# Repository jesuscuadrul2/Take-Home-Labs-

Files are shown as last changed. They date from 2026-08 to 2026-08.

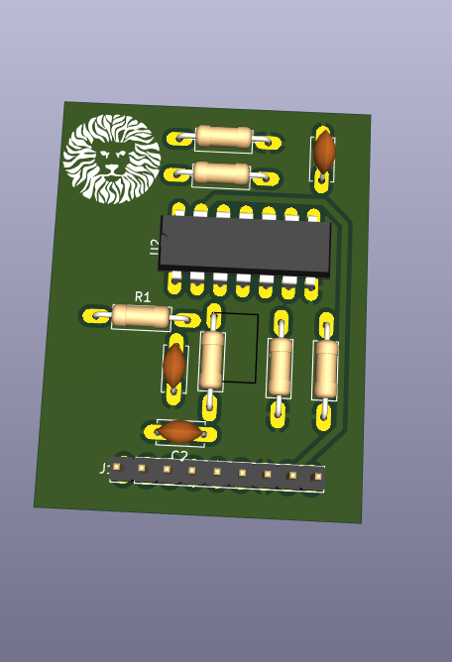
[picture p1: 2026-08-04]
Images/Planta_RC/3D View.png

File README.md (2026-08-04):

# 🔬 Take-Home Labs: Plataforma de Control con Arduino Mega (ATmega2560)






Este repositorio contiene el desarrollo, documentación y código fuente de una serie de laboratorios experimentales centrados en la arquitectura del microcontrolador ATmega2560. El proyecto se articula en torno a una **Shield personalizada diseñada en KiCad**, la cual integra tres plantas físicas intercambiables orientadas a la validación de estrategias de adquisición de señales, instrumentación y control en lazo cerrado.

## 🎯 Objetivo General

Desarrollar competencias avanzadas en la programación de sistemas embebidos priorizando el control directo del hardware a bajo nivel. El proyecto cierra la brecha entre el diseño electrónico (esquemáticos y PCB) y el desarrollo de firmware, validando iterativamente plantas físicas reales.

## 🛠️ Arquitectura de Hardware (KiCad PCB Shield)

La placa base fue diseñada con un enfoque altamente modular. La distribución de señales PWM, analógicas y digitales se realiza a través de **pin sockets modulares (como el conector principal J2 y los puertos dedicados J10, J13, J15)**, permitiendo acoplar diferentes plantas de manera dinámica. 

El sistema cuenta con una topología de potencia robusta:

*   **Gestión de Energía:** Entrada principal de 15V (vía Barrel Jack o PD Trigger) acondicionada a 12V mediante un regulador ajustable **LM350 (TO-220)**. 
*   **Regulación en Cascada:** Etapas secundarias aisladas a 5V (L7805) y 9V (L7809) provistas de capacitores de desacoplo para garantizar rizado mínimo en las etapas analógicas.
*   **Interfaz Humano-Máquina:** Integración en placa de un Encoder Rotativo con filtrado de hardware anti-rebote (redes RC de 100nF) para navegación de menús.

## 🕹️ Descripción Técnica de las Plantas

### 1. Planta de Enrutamiento y Dinámica (CD4066)

*   **Arquitectura:** Matriz de conmutación de señales analógicas basada en arreglos de interruptores bilaterales **CD4066BE**.
*   **Comportamiento Dinámico:** Integra tres redes RC en cascada (1 MΩ y 1 µF) controladas digitalmente con resistencias de *pulldown* (10k). Permite modificar la función de transferencia del sistema en tiempo real, ajustando la respuesta transitoria según las etapas activadas por el microcontrolador.

### 2. Planta Electromecánica (Motor DC N20)

*   **Actuación:** Modulación de velocidad mediante un MOSFET de canal N (Q1) excitado por señal PWM, con una resistencia de *pulldown* (10k) en la puerta y un diodo de giro libre (Flyback D7) para suprimir picos inductivos del motor a 12V.
*   **Telemetría:** Integración directa de un encoder de cuadratura que proporciona datos de posición y velocidad (conectado al header J10), habilitando la implementación de algoritmos PID en lazo cerrado.

### 3. Planta de Visualización e Instrumentación (LM3914N)

*   **Interfaz Visual:** Vúmetro analógico basado en el driver **LM3914N** alimentado a 9V, que excita una barra de 10 segmentos LED (HDSP-4830) de forma lineal.
*   **Acondicionamiento de Señal:** Para visualizar la salida digital del Arduino, incorpora un filtro pasa-bajas RC (resistencia de 4.7 kΩ y capacitor de 10 µF) que convierte el tren de pulsos PWM en una señal DC estable, garantizando una lectura continua sin parpadeos visuales. El rango de referencia es calibrable mediante un potenciómetro de 5k.

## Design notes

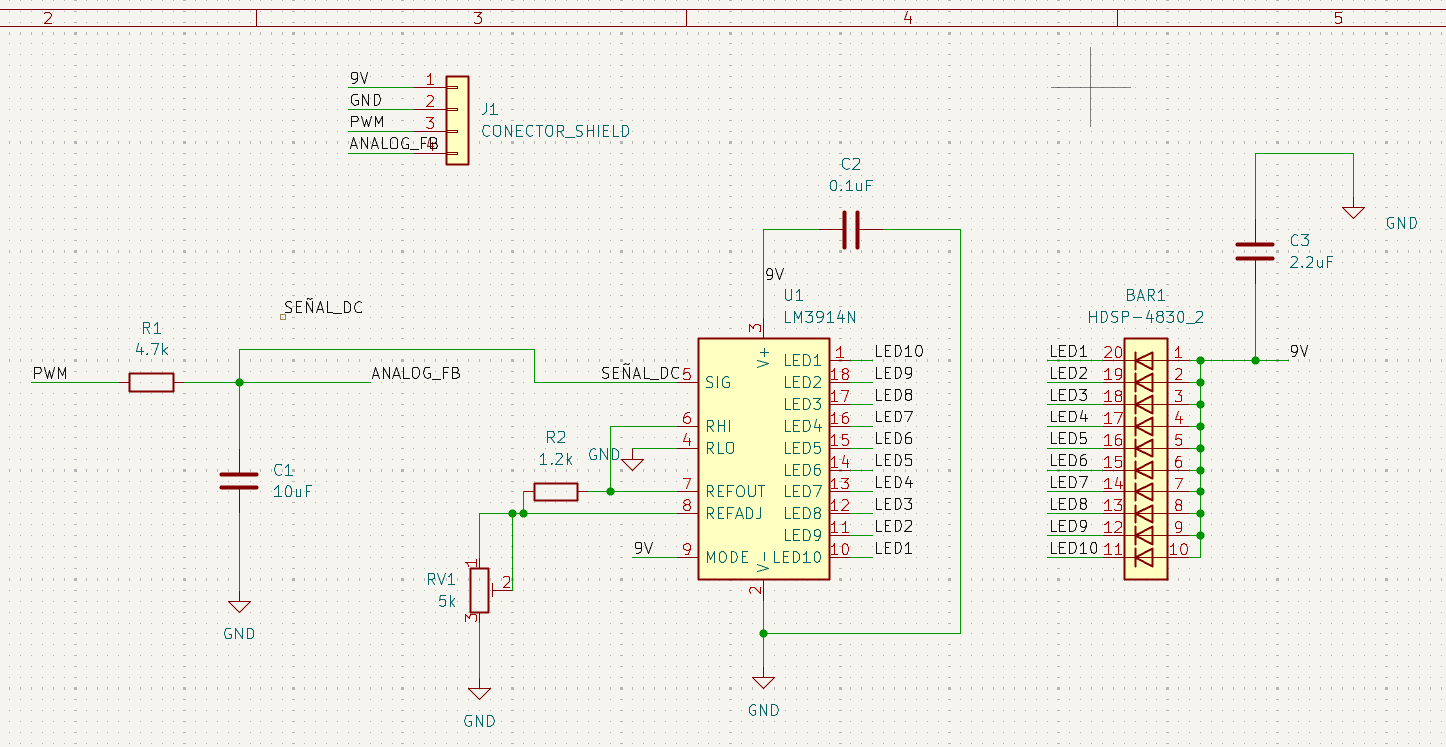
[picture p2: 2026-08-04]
Images/Planta_Barra_Led-/Schematics.png

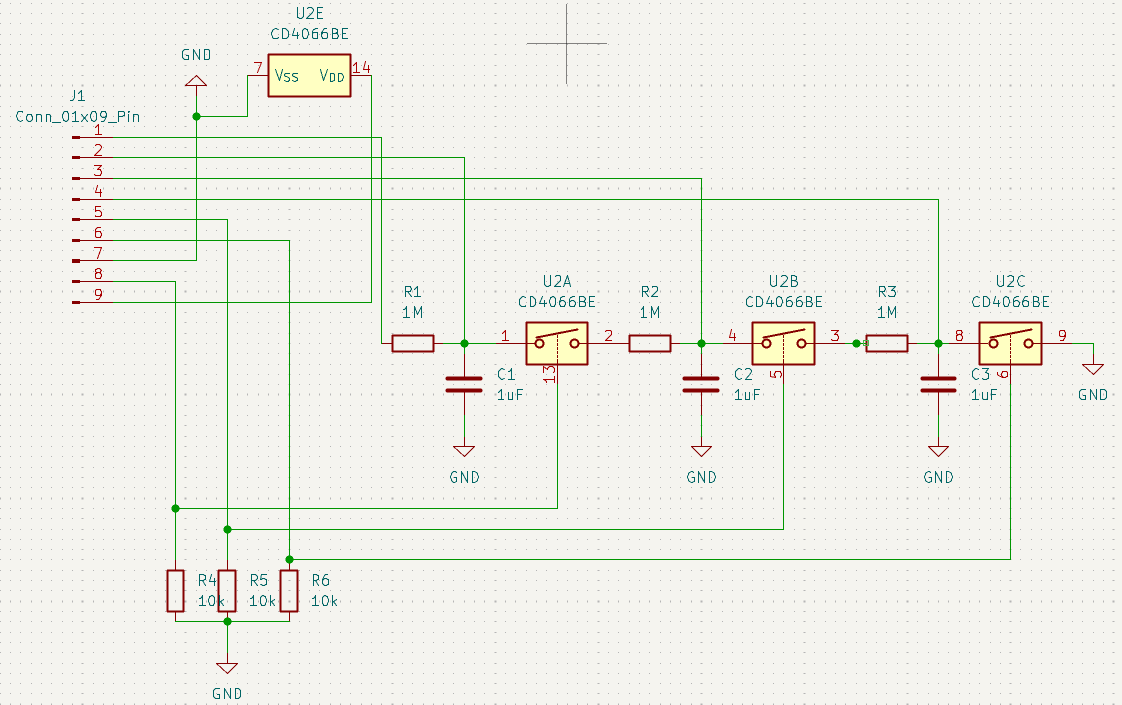
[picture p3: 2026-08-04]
Images/Planta_RC/Schematic.png

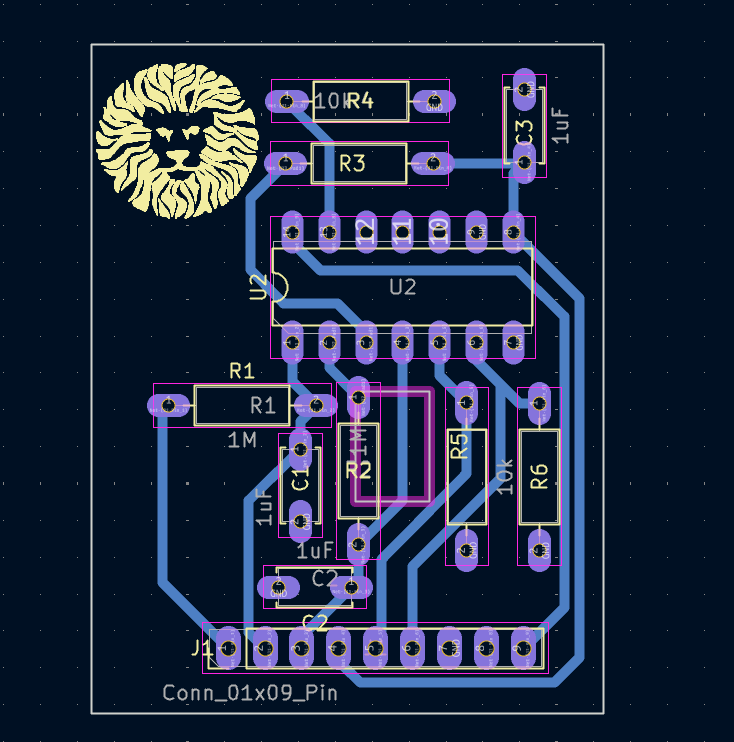
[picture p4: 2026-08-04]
Images/Planta_RC/Layout_Bottom.png

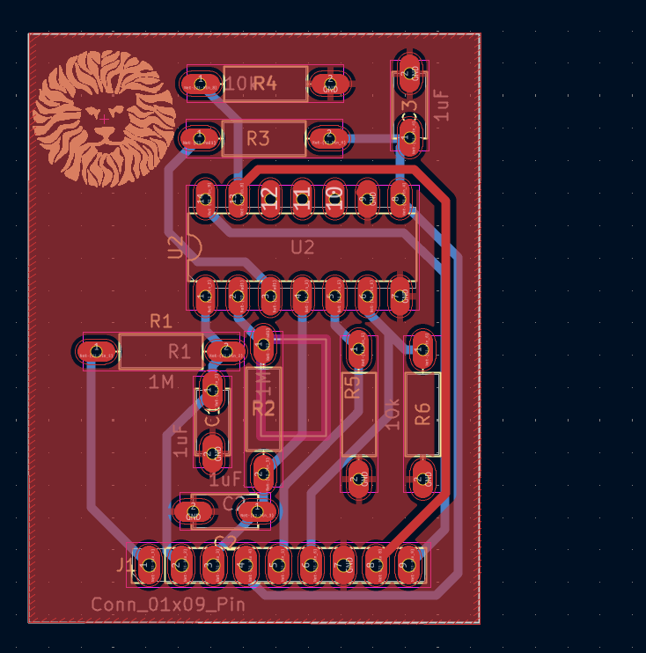
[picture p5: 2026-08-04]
Images/Planta_RC/Layout.png

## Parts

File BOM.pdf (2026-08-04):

## Lista de Materiales (BOM) – PCB Proyecto

TakeHomeLab

Shield Arduino Mega 2560 R3

### Componentes de la Placa Base (THT)

## Capacitores

- C1, C3, C8, C9,C6,C7 – 100nF – Capacitor cerámico disco -Footprint: C_Disc_D5.0mm_W2.5mm_P5.00mm
-Método de Soldado: THT
-Precio aproximado = $1.50 c/u
-Precio total= $9 pesos
- C2, C4, C12 – 100µF – Capacitor electrolítico radial -Footprint: CP_Radial_D6.3mm_P2.50mm
-Método de Soldado: THT
-Precio aproximado = $2.50 c/u
-Precio total= $7.5 pesos
- C5 – 1000µF / 25V – Capacitor electrolítico radial -Footprint: CP_Radial_D10.0mm_P5.00mm
-Método de Soldado: THT
-Precio aproximado = $5 pesos
- C10, C13, C14 – 1µF – Capacitor cerámico disco -Footprint: C_Disc_D5.0mm_W2.5mm_P5.00mm -Método de Soldado: THT
-Precio aproximado = $1.5 pesos
-Precio total: $ 4.5 pesos
- C11 – 10µF – Capacitor electrolítico radial -Footprint: CP_Radial_D5.0mm_P2.00mm -Método de Soldado: THT
-Precio aproximado = $2 pesos

## Diodos

- D1–D5 – 1N4007
-Footprint: D_DO-41_SOD81_P10.16mm_Horizontal -Método de Soldado: THT
-Precio aproximado = $1 c/u
-Precio total= $2 pesos
- D6 – 1N5408
-Footprint: D_DO-201AD_P15.24mm_Horizontal -Método de Soldado: THT
-Precio Total= $3 pesos

## Resistencias

- R1, R3, – 330 – Axial 1/4W Ω
-Footprint: R_Axial_DIN0309_L9.0mm_D3.2mm_P12.70mm_Horizontal -Método de Soldado: THT
-Precio aproximado = $0.50 c/u
-Precio total= $1 peso
- R2, R4, R7, R10– 120 – Axial 1/4W Ω
-Footprint: R_Axial_DIN0309_L9.0mm_D3.2mm_P12.70mm_Horizontal -Método de Soldado: THT
--Precio aproximado = $0.50 c/u
-Precio total= $2 pesos
- R5,R6 – 33 – Axial 1/4W Ω
-Footprint: R_Axial_DIN0309_L9.0mm_D3.2mm_P12.70mm_Horizontal -Método de Soldado: THT
-Precio aproximado = $0.50 c/u
-Precio total= $1 peso
- R9 – 750 – Axial 1/4W Ω
-Footprint: R_Axial_DIN0309_L9.0mm_D3.2mm_P12.70mm_Horizontal -Método de Soldado: THT
-Precio Aproximado= $0.5 pesos
- R15, R16, R17 – 10k – Axial 1/4W Ω
-Footprint: R_Axial_DIN0207_L6.3mm_D2.5mm_P10.16mm_Horizontal

-Método de Soldado: THT
-Precio Aproximado: $0.5 c/u
-Precio Total= $1.5 pesos
- R18, R19, R20– 1M – Axial 1/4W Ω
-Footprint: R_Axial_DIN0207_L6.3mm_D2.5mm_P10.16mm_Horizontal -Método de Soldado: THT
-Precio Aproximado: $0.5 c/u
-Precio Total= $1.5 pesos
- R8 – 1k – Axial 1/4W Ω
-Footprint: R_Axial_DIN0207_L6.3mm_D2.5mm_P10.16mm_Horizontal -Método de Soldado: THT
-Precio Aproximado: $0.5 pesos

## Conectores

-PinSocket_1x09_P2.54mm_Vertical (Planta RC) -Precio aproximado= $ 2 pesos
-Pin socket_1x06_P2.54mm_Vertical (Planta MotorDC) -Precio aproximado= $ 2 pesos
-PinSocket_1x04_P2.54mm_Vertical (Display)
-Precio aproximado= $ 2 pesos

-Connector_PinHeader_2.54mm:PinHeader_1x08_P2.54mm_Vertical(Arduino Mega) -Precio aproximado= $ 2 pesos c/u
-Precio Total= $12 pesos
-Connector_PinHeader_2.54mm:PinHeader_2x18_P2.54mm_Vertical
-Precio aproximado= $ 5 pesos

-Barrel Jack horizontal
-Precio aproximado= $5 pesos

-Encoder Rotatorio con Switch (ec11) -Precio aproximado= $40 pesos

## Circuitos Integrados

- U1, U2, U4, U5 – LM350 – Encapsulado TO-220-3 -Footprint: TO-220-3_Vertical
-Método de Soldado: THT
-precio aproximado: $ 36 a 60 pesos
Precio Total= 160 pesos
- U6 – CD4066BE – Encapsulado DIP-14 -Footprint: DIP-14_W7.62mm
-Método de Soldado: THT
Precio estimado= $9 pesos
- TO-220 Disipador de Calor Aluminio (Se usaran 4) -Precio aproximado: $8 c/u
-Precio Total= $32 pesos

## Módulos Externos (No Soldables)

- Arduino Mega 2560 R3 Atmega16u2 Sin Cable
-Precio aproximado= $360-370 pesos
- Display OLED 0.96 Pulgadas Amarillo Con Azul I2C 128x64 -Precio estimado=$90-100 pesos
- Cargador DC 15V 3A
-Precio estimado=$250 a 300 pesos

## Módulos Externos (Plantas)

Planta RC

Circuitos Integrados
- U2 – CD4066BE – Quad Bilateral Switch (Interruptor Analógico CMOS)
ü -Footprint: Package_DIP:DIP-14_W7.62mm
ü -Método de Soldado: THT (Se recomienda comprarle una base socket de 14 pines para no soldar el chip directo)
-Precio aproximado = $15.00 c/u
-Precio total= $15.00 pesos

Resistencias

ü R1, R2, R3 – 1M – Resistencia de película de carbón o metal 1/4W Ω ü -Footprint: Resistor_THT:R_Axial_DIN0207_L6.3mm_D2.5mm_P10.16mm_Horizontal -ü Método de Soldado: THT
-Precio aproximado = $1.00 c/u
-Precio total= $3.00 pesos

ü R4, R5, R6 – 10k – Resistencia de película de carbón o metal 1/4W Ω
ü -Footprint: Resistor_THT:R_Axial_DIN0207_L6.3mm_D2.5mm_P10.16mm_Horizontal -ü Método de Soldado: THT
-Precio aproximado = $1.00 c/u
-Precio total= $3.00 pesos

Capacitores

ü C1, C2, C3 – 1µF – Capacitor de poliéster o cerámico multicapa
ü -Footprint: Capacitor_THT:C_Rect_L7.0mm_W2.5mm_P5.00mm (o similar dependiendo si compras de cajita o lenteja)
ü -Método de Soldado: THT
-Precio aproximado = $3.00 c/u
-Precio total= $9.00 pesos

Conectores

ü J1 – Conn_01x09_Pin – Tira de pines macho (Pin Header) paso 2.54mm
ü -Footprint: Connector_PinHeader_2.54mm:PinHeader_1x09_P2.54mm_Vertical
ü -Método de Soldado: THT
-Precio aproximado = $10.00 c/u (Normalmente te venden la tira completa de 40 pines y tú cortas los 9 que necesitas) -Precio total= $10.00 pesos

Planta Motor con Encoder

Actuador (El Músculo)
Motor – JGA25-370 (o GM25-370) de 12V con Encoder Magnético
- Nota de diseño: Es el estándar de batalla. Te dará buena resolución para medir las RPM y buen torque.
- Método de montaje: Externo (conectado mediante su mazo de cables al JST-XH).
- Precio aproximado: $250.00 a $350.00 MXN (depende de si lo compras en MercadoLibre o tiendas locales).
- Precio total: ~$300.00 pesos

Semiconductores (Elección de Ingeniería)

Q1 – IRLZ44N (o IRLB8721) – MOSFET Canal N (Logic-Level)
- Footprint: Package_TO_SOT_THT:TO-220-3_Vertical
- Método de Soldado: THT (Te recomiendo ponerle un disipador pequeño por precaución, aunque con este MOSFET suele mantenerse muy frío).
- Precio aproximado: $25.00 c/u
- Precio total: $25.00 pesos
D7 – 1N5819 – Diodo Flyback / Rueda Libre
- Footprint: Diode_THT:D_DO-41_SOD81_P10.16mm_Horizontal
- Método de Soldado: THT
- Precio aproximado: $2.00 c/u
- Precio total: $2.00 pesos

Pasivos

R11 – 10k – Resistencia pulldown de película de carbón 1/4W Ω
- Nota de diseño: Mantiene el motor apagado mientras el Arduino se reinicia.
- Footprint:
Resistor_THT:R_Axial_DIN0207_L6.3mm_D2.5mm_P10.16mm_Horizont al
- Método de Soldado: THT
- Precio aproximado: $1.00 c/u
- Precio total: $1.00 pesos

Conectores

J1 (Conector Shield) – Conn_01x06_Pin – Tira de pines macho
- Footprint:
Connector_PinHeader_2.54mm:PinHeader_1x06_P2.54mm_Vertical
- Método de Soldado: THT
- Precio aproximado: $10.00 c/u (Comprando la tira de 40 pines y cortando 6).
- Precio total: $10.00 pesos
J2 (M_ENCODER) – JST-XH de 6 pines (Macho para placa)
- Footprint: Connector_JST:JST_XH_B6B-XH-A_1x06_P2.50mm_Vertical
- Método de Soldado: THT
- Precio aproximado: $8.00 c/u (Suelen vender el par macho-hembra con cables integrados, lo cual te sirve perfecto si tu motor viene con los cables pelados).
- Precio total: $8.00 pesos

Presupuesto Total Estimado
Los precios son aproximados y pueden variar dependiendo del proveedor (Steren, AG Electr ´onica, MercadoLibre, etc.). El costo de fabricación del PCB (fibra de vidrio) no está incluido
Categoria | Costo Estimado MXN
Componentes de Placa Base | $310
Modulos Externos | $700-770
Planta RC | $40
Planta Motor | $346
Costo total del proyecto | $1,396.00 - $1,466.00

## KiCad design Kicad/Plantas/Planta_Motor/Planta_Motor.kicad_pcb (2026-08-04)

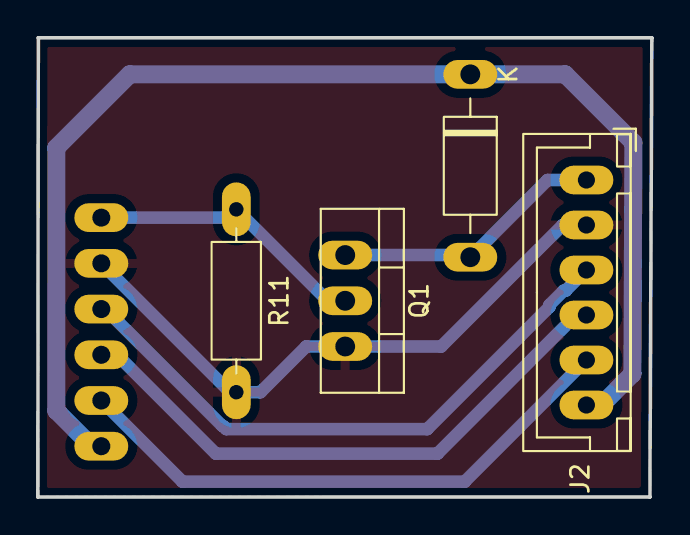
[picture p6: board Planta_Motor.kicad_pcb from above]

Board: 2 copper layers, 34.1 x 25.5 mm, 5 parts (1 on the bottom side), 7 nets.

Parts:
D7: D; D_DO-41_SOD81_P10.16mm_Horizontal
J1: CONECTOR SHIELD; PinHeader_1x06_P2.54mm_Vertical
J2: M_ENCODER; JST_XH_B6B-XH-A_1x06_P2.50mm_Vertical
Q1: NMOS; TO-220-3_Vertical
R11: 10k; R_Axial_DIN0207_L6.3mm_D2.5mm_P10.16mm_Horizontal

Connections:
12V: D7.1 (K), J1.6, J2.6
/5V: J1.5, J2.5
/Drain: D7.2 (A), J2.1, Q1.e (D)
/ENCODER_A: J1.3, J2.3
/ENCODER_B: J1.4, J2.4
/PWM: J1.1, Q1.2 (G), R11.1
GND: J1.2, J2.2, Q1.3 (S), R11.2

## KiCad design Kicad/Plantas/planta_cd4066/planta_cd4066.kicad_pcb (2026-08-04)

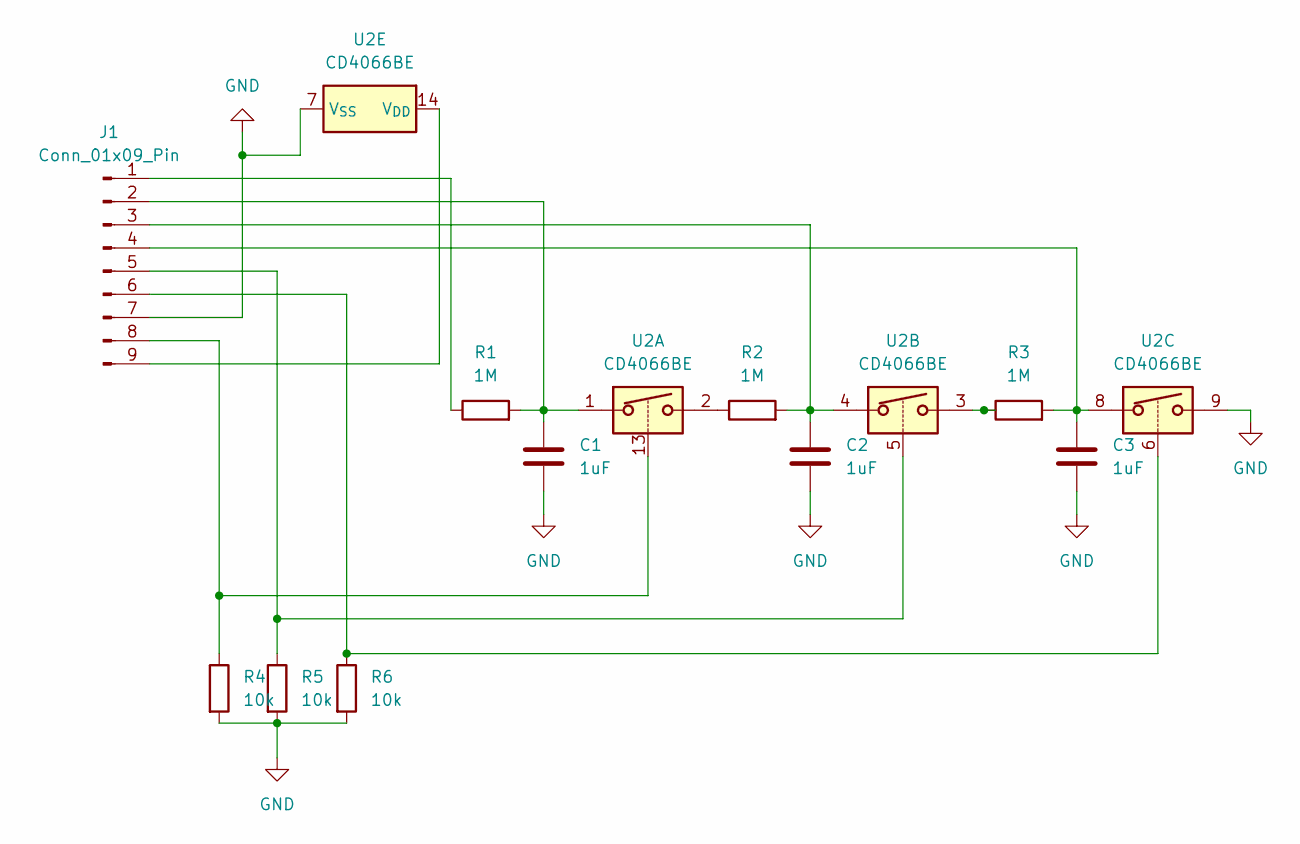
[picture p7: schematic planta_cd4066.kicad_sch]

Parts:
C1, C2, C3: 1uF; C_Disc_D5.0mm_W2.5mm_P5.00mm
J1: Conn_01x09_Pin; PinHeader_1x09_P2.54mm_Vertical
R1, R2, R3: 1M; R_Axial_DIN0207_L6.3mm_D2.5mm_P10.16mm_Horizontal
R4, R5, R6: 10k; R_Axial_DIN0207_L6.3mm_D2.5mm_P10.16mm_Horizontal
U2: CD4066BE; DIP-14_W7.62mm

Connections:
GND: C1.2, C2.2, C3.2, J1.7, R4.2, R5.2, R6.2, U2.7 (V_{SS}), U2.9
unnamed: J1.1, R1.1
unnamed: C1.1, J1.2, R1.2, U2.1
unnamed: C2.1, J1.3, R2.2, U2.4
unnamed: C3.1, J1.4, R3.2, U2.8
unnamed: J1.5, R5.1, U2.5
unnamed: J1.6, R6.1, U2.6
unnamed: J1.8, R4.1, U2.13
unnamed: J1.9, U2.14 (V_{DD})
unnamed: R2.1, U2.2
unnamed: R3.1, U2.3

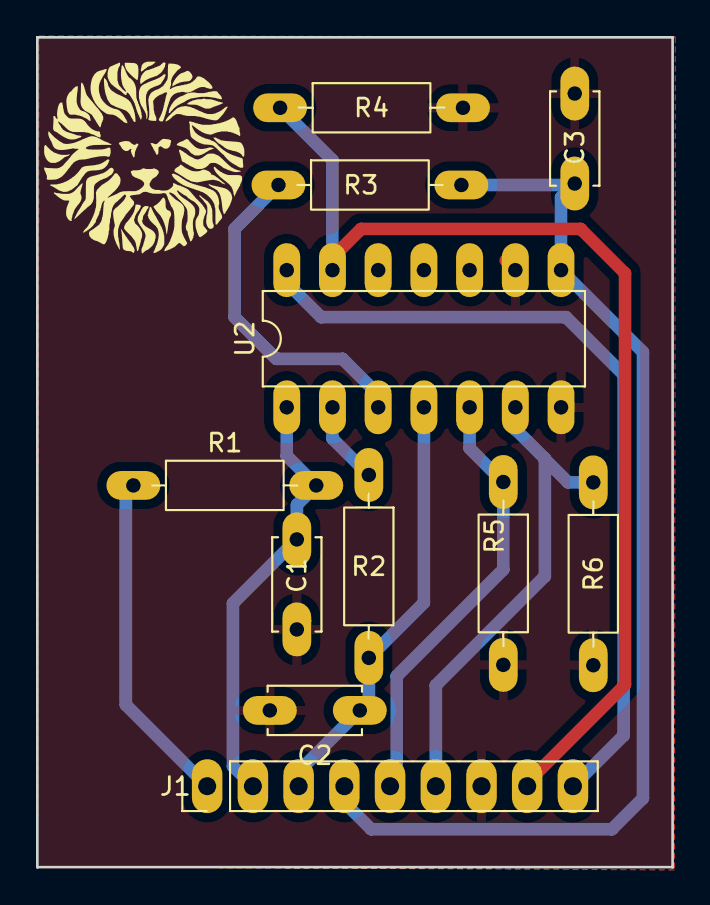
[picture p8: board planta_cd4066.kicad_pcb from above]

Board: 2 copper layers, 35.3 x 46.1 mm, 11 parts (0 on the bottom side), 11 nets.

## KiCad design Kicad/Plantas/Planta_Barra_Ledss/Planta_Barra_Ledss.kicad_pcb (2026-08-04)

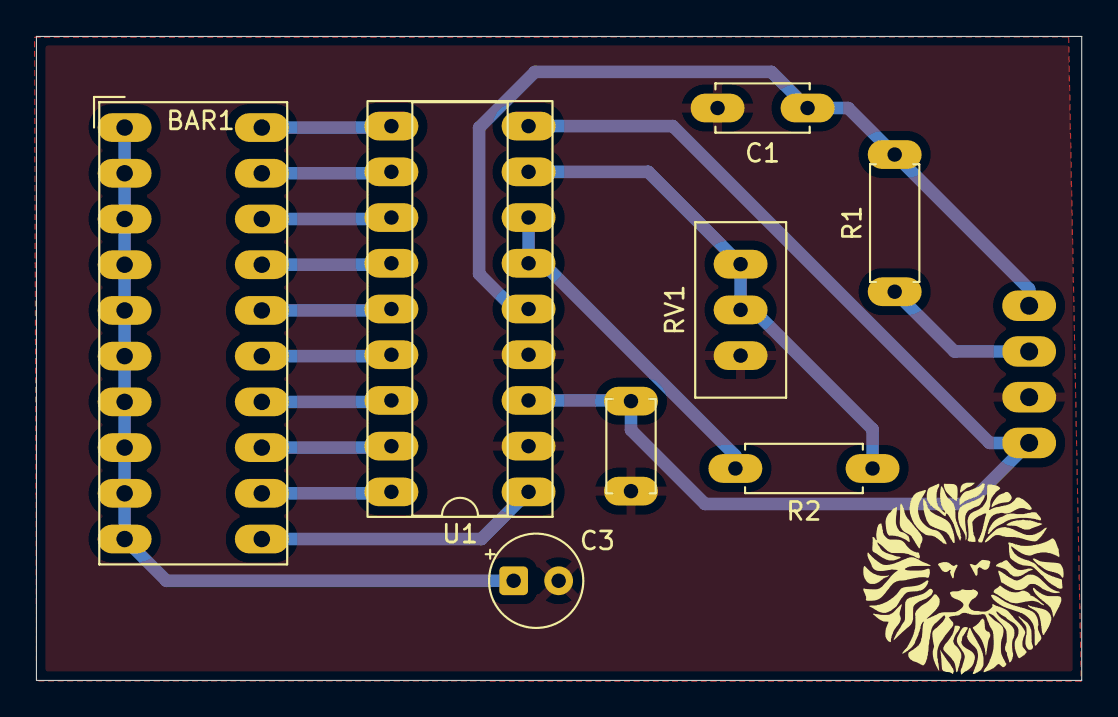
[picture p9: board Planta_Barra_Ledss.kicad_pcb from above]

Board: 2 copper layers, 58.1 x 35.8 mm, 9 parts (1 on the bottom side), 16 nets.

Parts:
BAR1: HDSP-4830_2; HDSP-4830
C1: 10uF; C_Disc_D5.0mm_W2.5mm_P5.00mm
C2: 0.1uF; C_Disc_D5.0mm_W2.5mm_P5.00mm
C3: 2.2uF; CP_Radial_Tantal_D5.0mm_P2.50mm
J1: CONECTOR_SHIELD; PinHeader_1x04_P2.54mm_Vertical
R1: 4.7k; R_Axial_DIN0207_L6.3mm_D2.5mm_P7.62mm_Horizontal
R2: 1.2k; R_Axial_DIN0207_L6.3mm_D2.5mm_P7.62mm_Horizontal
RV1: 5k; Potentiometer_Bourns_3296W_Vertical
U1: LM3914N; DIP-18_W7.62mm_Socket

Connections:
/9V: BAR1.1 (A), BAR1.2 (A), BAR1.3 (A), BAR1.4 (A), BAR1.5 (A), BAR1.6 (A), BAR1.7 (A), BAR1.8 (A), BAR1.9 (A), BAR1.10 (A), C2.1, C3.1, J1.1, U1.3 (V+), U1.9 (MODE)
/ANALOG_FB: J1.4, R1.2, U1.5 (SIG)
/LED1: BAR1.20 (K), U1.10 (LED10)
/LED2: BAR1.19 (K), U1.11 (LED9)
/LED3: BAR1.18 (K), U1.12 (LED8)
/LED4: BAR1.17 (K), U1.13 (LED7)
/LED5: BAR1.16 (K), U1.14 (LED6)
/LED6: BAR1.15 (K), U1.15 (LED5)
/LED7: BAR1.14 (K), U1.16 (LED4)
/LED8: BAR1.13 (K), U1.17 (LED3)
/LED9: BAR1.12 (K), U1.18 (LED2)
/LED10: BAR1.11 (K), U1.1 (LED1)
/PWM: J1.3, R1.1
GND: C1.2, C3.2, J1.2, RV1.3, U1.2 (V-), U1.4 (RLO)
unnamed: R2.1, RV1.1, RV1.2, U1.8 (REFADJ)
unnamed: R2.2, U1.6 (RHI), U1.7 (REFOUT)

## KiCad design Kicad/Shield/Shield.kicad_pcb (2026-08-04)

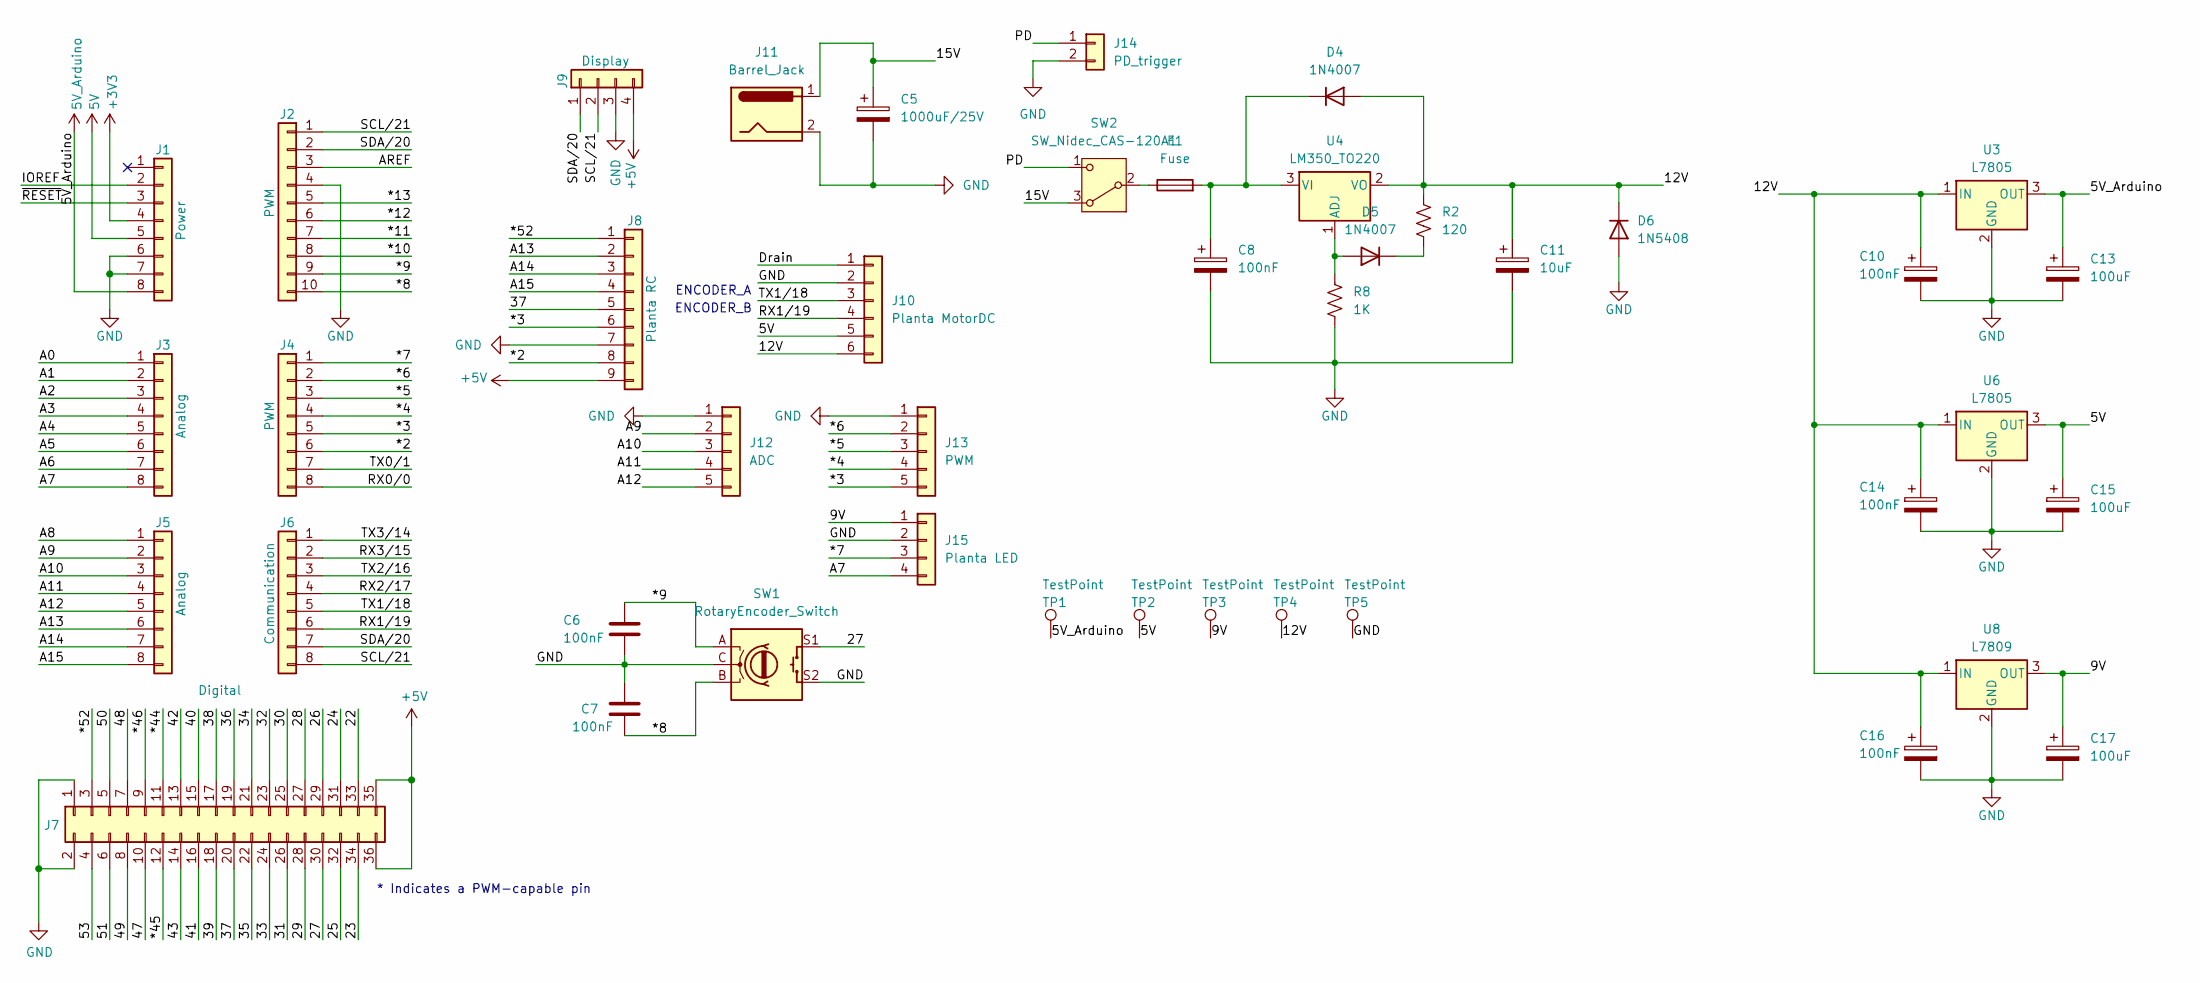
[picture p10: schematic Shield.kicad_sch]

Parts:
C5: 1000uF/25V; CP_Radial_D10.0mm_P5.00mm
C6, C7: 100nF; C_Disc_D5.0mm_W2.5mm_P5.00mm
C8, C10, C14, C16: 100nF; CP_Radial_Tantal_D5.0mm_P2.50mm
C11: 10uF; CP_Radial_D5.0mm_P2.00mm
C13, C15, C17: 100uF; CP_Radial_D6.3mm_P2.50mm
D4, D5: 1N4007; D_DO-41_SOD81_P10.16mm_Horizontal
D6: 1N5408; D_DO-201AD_P15.24mm_Horizontal
F1: Fuse; Fuseholder_Cylinder-5x20mm_Schurter_0031_8201_Horizontal_Op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
J1: Power; PinHeader_1x08_P2.54mm_Vertical
J2: PWM; PinHeader_1x10_P2.54mm_Vertical
J3, J5: Analog; PinHeader_1x08_P2.54mm_Vertical
J4: PWM; PinHeader_1x08_P2.54mm_Vertical
J6: Communication; PinHeader_1x08_P2.54mm_Vertical
J7: Digital; PinHeader_2x18_P2.54mm_Vertical
J8: Planta RC; PinSocket_1x09_P2.54mm_Vertical
J9: Display; PinSocket_1x04_P2.54mm_Vertical
J10: Planta MotorDC; PinSocket_1x06_P2.54mm_Vertical
J11: Barrel_Jack; BarrelJack_Horizontal
J12: ADC; PinSocket_1x05_P2.54mm_Vertical
J13: PWM; PinSocket_1x04_P2.54mm_Vertical
J14: PD_trigger; PinHeader_1x02_P2.54mm_Vertical
J15: Planta LED; PinSocket_1x04_P2.54mm_Vertical
R2: 120; R_Axial_DIN0309_L9.0mm_D3.2mm_P12.70mm_Horizontal
R8: 1K; R_Axial_DIN0309_L9.0mm_D3.2mm_P12.70mm_Horizontal
SW1: RotaryEncoder_Switch; RotaryEncoder_Alps_EC11E-Switch_Vertical_H20mm
SW2: SW_Nidec_CAS-120A1; PinHeader_1x03_P2.54mm_Vertical
TP1, TP2, TP3, TP4, TP5: TestPoint; TestPoint_Pad_2.0x2.0mm
U3, U6: L7805; TO-220-3_Vertical
U4: LM350_TO220; TO-220-3_Vertical
U8: L7809; TO-220-3_Vertical

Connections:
5V: C15.1, J1.5, J10.5, TP2.1, U6.3 (OUT)
5V_Arduino: C13.1, J1.8, TP1.1, U3.3 (OUT)
+3V3: J1.4
+5V: J7.35, J7.36, J8.9, J9.4
/9V: C17.1, J15.1, TP3.1, U8.3 (OUT)
/15V: C5.1, J11.1, SW2.3 (A)
/22: J7.33
/23: J7.34
/24: J7.31
/25: J7.32
/26: J7.29
/27: J7.30, SW1.S1
/28: J7.27
/29: J7.28
/30: J7.25
/31: J7.26
/32: J7.23
/33: J7.24
/34: J7.21
/35: J7.22
/36: J7.19
/37: J7.20, J8.5
/38: J7.17
/39: J7.18
/40: J7.15
/41: J7.16
/42: J7.13
/43: J7.14
/47: J7.10
/48: J7.7
/49: J7.8
/50: J7.5
/51: J7.6
/53: J7.4
/*2: J4.6, J8.8
/*3: J4.5, J8.6, J13.5
/*4: J4.4, J13.4
/*5: J4.3, J13.3
/*6: J4.2, J13.2
/*7: J4.1, J15.3
/*8: C7.2, J2.10, SW1.B
/*9: C6.1, J2.9, SW1.A
/*10: J2.8
/*11: J2.7
/*12: J2.6
/*13: J2.5
/*44: J7.11
/*45: J7.12
/*46: J7.9
/*52: J7.3, J8.1
/A0: J3.1
/A1: J3.2
/A2: J3.3
/A3: J3.4
/A4: J3.5
/A5: J3.6
/A6: J3.7
/A7: J3.8, J15.4
/A8: J5.1
/A9: J5.2, J12.2
/A10: J5.3, J12.3
/A11: J5.4, J12.4
/A12: J5.5, J12.5
/A13: J5.6, J8.2
/A14: J5.7, J8.3
/A15: J5.8, J8.4
/AREF: J2.3
/Drain: J10.1
/IOREF: J1.2
/PD: J14.1, SW2.1 (C); also elsewhere on the board
/RX0/0: J4.8
/RX1/19: J6.6, J10.4
/RX2/17: J6.4
/RX3/15: J6.2
/SCL/21: J2.1, J6.8, J9.2
/SDA/20: J2.2, J6.7, J9.1
/TX0/1: J4.7
/TX1/18: J6.5, J10.3
/TX2/16: J6.3
/TX3/14: J6.1
/~RESET: J1.3
GND: C5.2, C6.2, C7.1, C8.2, C10.2, C11.2, C13.2, C14.2, C15.2, C16.2, C17.2, D6.2 (A), J1.6, J1.7, J2.4, J7.1, J7.2, J8.7, J9.3, J10.2, J11.2, J12.1, J13.1, J14.2, J15.2, R8.2, SW1.C, SW1.S2, TP5.1, U3.2 (GND), U6.2 (GND), U8.2 (GND); also elsewhere on the board
unnamed: C8.1, D4.1 (K), F1.2, U4.3 (VI)
unnamed: D5.2 (A), R8.1, U4.1 (ADJ)
unnamed: D5.1 (K), R2.2
unnamed: F1.1, SW2.2 (B)

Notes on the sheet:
ENCODER_B
ENCODER_A
* Indicates a PWM-capable pin

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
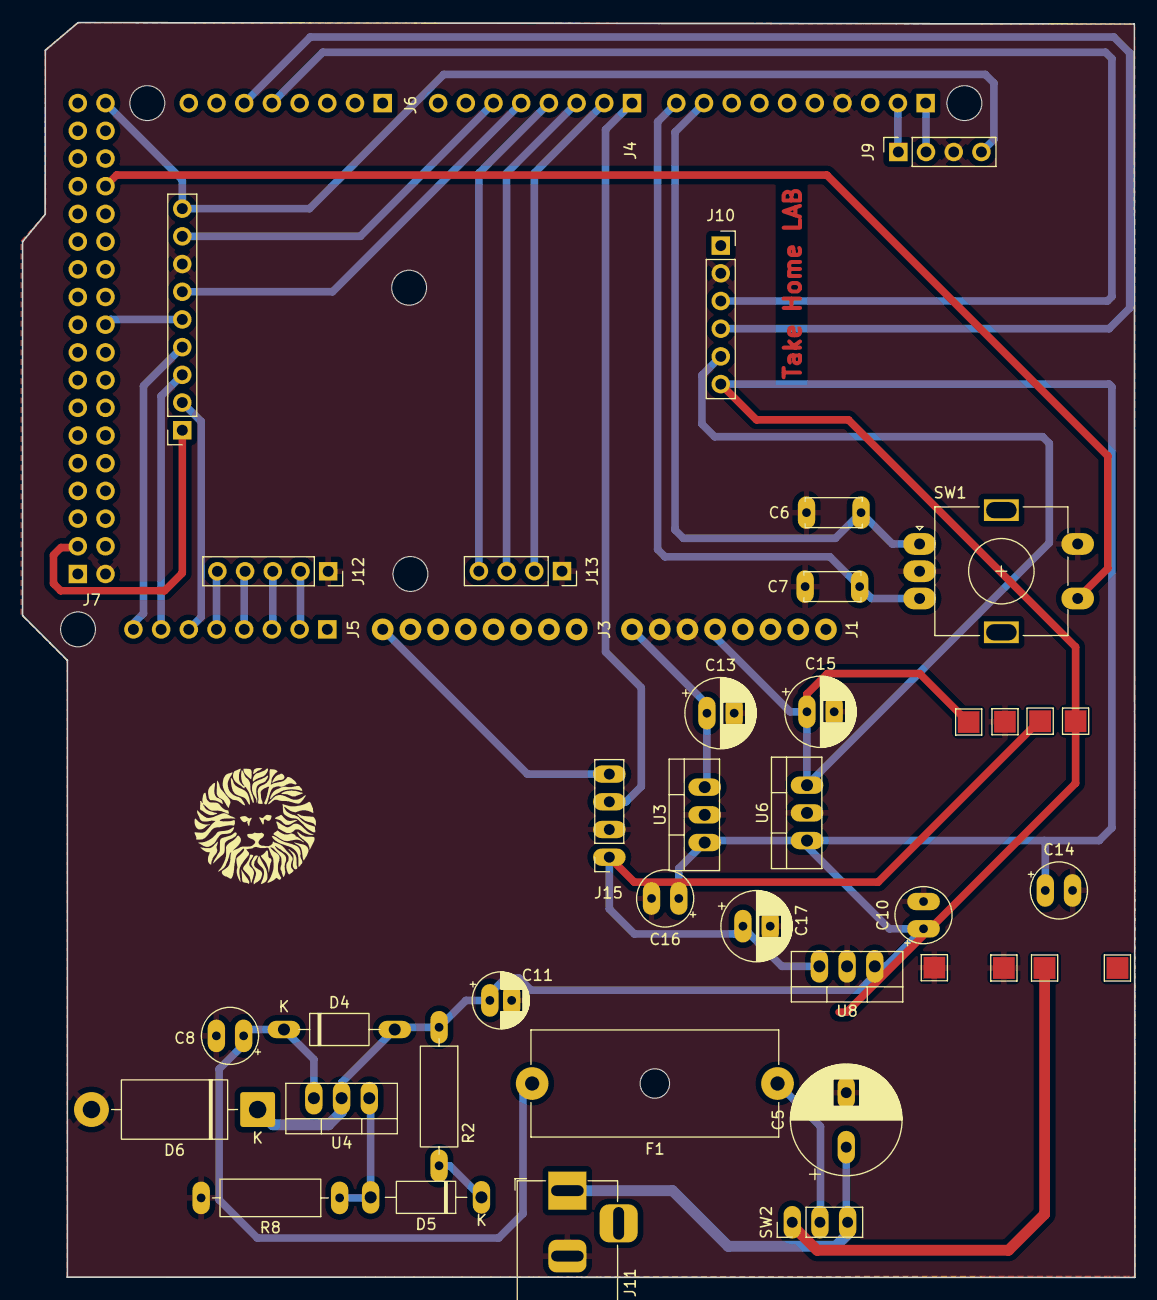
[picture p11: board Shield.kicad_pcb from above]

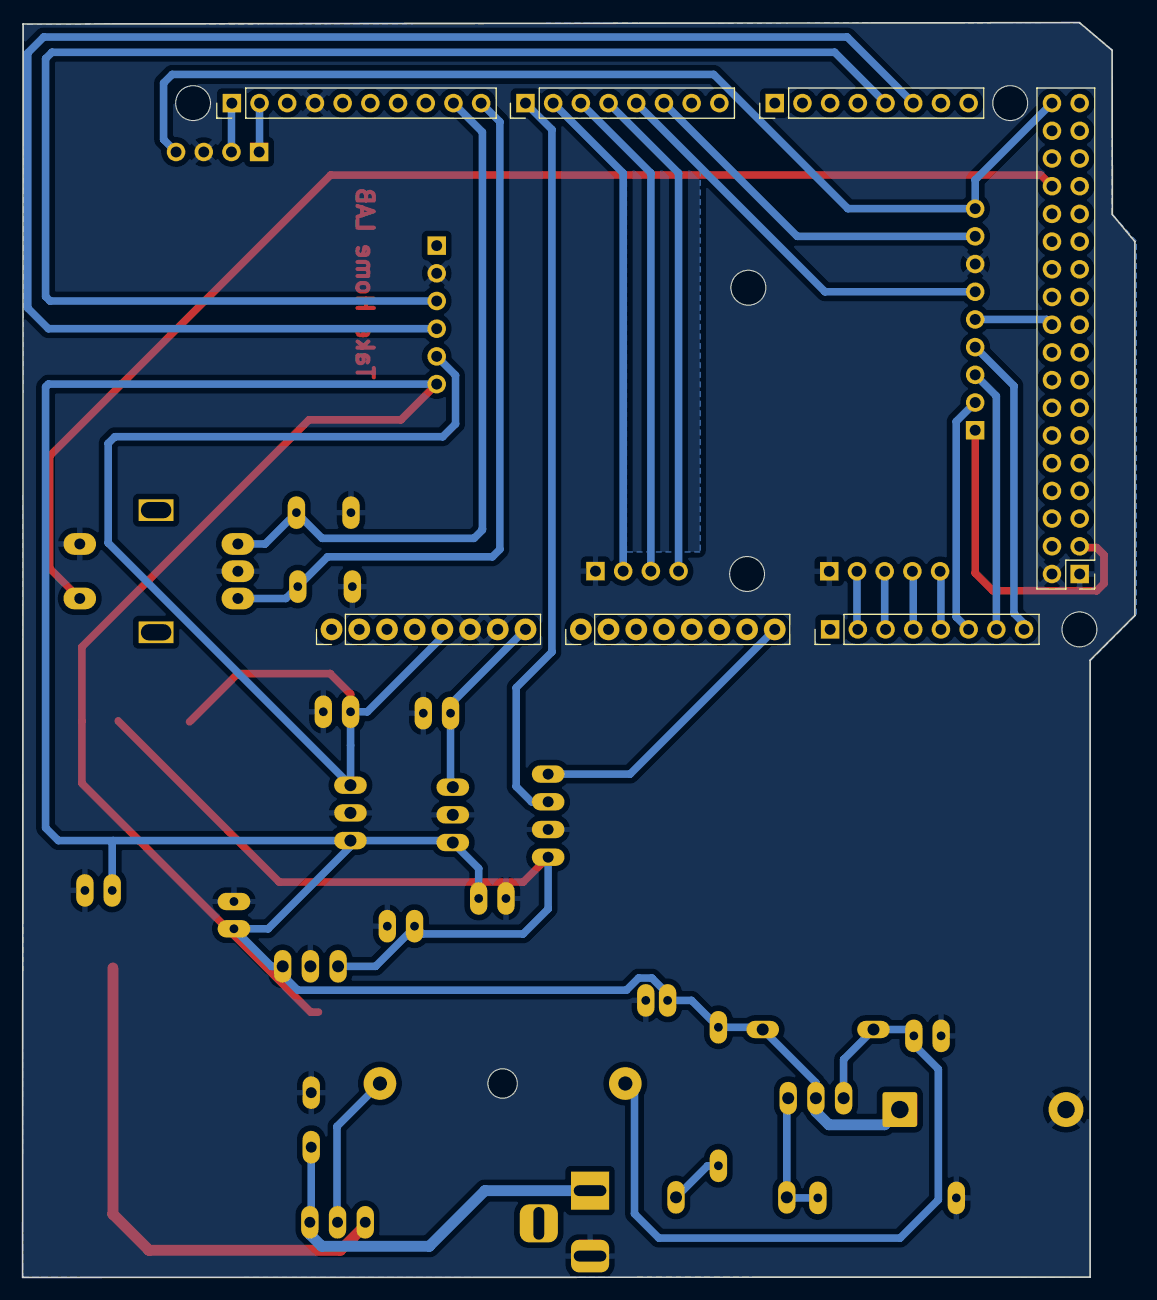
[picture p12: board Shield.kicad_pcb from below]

Board: 2 copper layers, 102.0 x 115.1 mm, 50 parts (12 on the bottom side), 35 nets.

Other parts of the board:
MH1, MH3, MH4, MH5, MH6: MountingHole_3.2mm
TP5#2, TP5#3, TP5#4, TP5#5: TestPoint; TestPoint_Pad_2.0x2.0mm

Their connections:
/PD: TP5#2.1, TP5#3.1; also elsewhere on the board
GND: TP5#4.1, TP5#5.1; also elsewhere on the board
